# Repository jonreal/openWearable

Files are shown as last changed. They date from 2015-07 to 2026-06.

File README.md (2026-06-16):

# openWearable

A real-time hardware/software platform for wearable robotics development based on the BeagleBone platform.

## Overview

openWearable is an open-source project designed to provide a complete hardware and software solution for developing wearable robotic systems, with a focus on real-time control. The platform utilizes the TI BeagleBone Black's Programmable Real-time Units (PRUs) to achieve deterministic high-speed control loops alongside a full Linux environment.

Current/past applications include:
- Upper limb soft exosuits
- Powered ankle-foot prostheses
- Haptic feedback systems
- EMG/IMU sensing and processing

## Getting Started

### Hardware Requirements
- BeagleBone Black or BeagleBone AI64 (see arm64 branch)
- Compatible sensors (see hardware directory)
- Actuators (PAMs, motors, etc.)

### Software Dependencies
- Recommended OS: Debian Linux 12.x (Bookworm) or later
- Kernel: 5.10.168-ti-r72
- PRU Code Generation Tools

### Installation

1. Clone the repository:
   ```
   git clone https://github.com/jonreal/openWearable.git
   cd openWearable
   ```

2. Build the library first:
   ```
   cd library && make
   ```

3. Build an application:
   ```
   cd ../apps/template && make
   ```

4. Run the application:
   ```
   ./bin/template
   ```

### Device Tree Setup

The device tree configures BeagleBone hardware resources for openWearable. Follow these steps:

1. Clone the BeagleBoard-DeviceTrees repository:
   ```
   git clone https://github.com/beagleboard/BeagleBoard-DeviceTrees.git ~/BeagleBoard-DeviceTrees
   ```

2. Create a symbolic link to your device tree file:

   For BeagleBone Black:
   ```
   cd device-tree
   ln -s $PWD/am335x-boneblack-openWearable.dts ~/BeagleBoard-DeviceTrees/src/arm/
   ```

   For BeagleBone Blue:
   ```
   cd device-tree
   ln -s $PWD/am335x-boneblue-openWearable.dts ~/BeagleBoard-DeviceTrees/src/arm/
   ```

3. Compile and install the device tree:
   ```
   cd ~/BeagleBoard-DeviceTrees
   make install_arm
   ```

4. The compiled device tree files will be installed to `/boot/dtbs/<kernel>/`
   (e.g., `/boot/dtbs/5.10.168-ti-r72/`)

5. Edit `/boot/uEnv.txt` to enable the overlay:
   ```
   sudo nano /boot/uEnv.txt
   ```
   
   Add or modify the following line:
   ```
   dtb=am335x-boneblack-openWearable.dtb   # For BeagleBone Black
   # OR
   dtb=am335x-boneblue-openWearable.dtb    # For BeagleBone Blue
   ```

6. Reboot the BeagleBone:
   ```
   sudo reboot
   ```

## Network Setup
To connect to the BeagleBone to Wi-Fi, follow these steps:
   ```
   iwctl

    [iwctl]# station wlan0 scan
    [iwctl]# station wlan0 get-networks
    [iwctl]# station wlan0 connect <SSID>

   ```

## Project Structure

- `apps/` - Application examples and templates
  - `template/` - Starting point for new applications
  - Various application examples (see below)
- `library/` - Core libraries
  - `include/` - Header files
  - `src/` - CPU-side source files
  - `pru_src/` - PRU-specific source files
- `device-tree/` - Hardware configuration
- `hardware/` - PCB designs and hardware documentation
- `gui/` - Visualization tools
- `utils/` - Utility programs
- `scripts/` - Helper scripts

## Application Development

Each application consists of these core files:
- `state.h` - Memory structure definitions
- `format.c` - Logging format definitions
- `cpuloop.c` - Application CPU logic
- `uiloop.c` - User interface logic
- `pruloop.c` - PRU-specific logic

To create a new application, copy the template directory:
```
cd apps
cp -r template my_new_app
cd my_new_app
```

### Build Commands
- First build the library: `cd library && make`
- Then build the app: `cd apps/[app-name] && make`

## Recent Enhancements

1. **Build System Reorganization (March 2025)**
   - Implemented libowpru.a for sharing PRU driver code
   - Each app links against this shared library
   
2. **DMA for Data Transfer (March 2025)**
   - Added DMA support for logging with performance monitoring
   - Use `-d` flag to disable DMA for benchmarking

3. **Binary Logging (In Progress)**
   - Converting text-based logs to binary format
   - Improving performance by reducing formatting overhead

## Example Applications

- **pamtest**: Test pneumatic artificial muscles (PAMs)
- **haptic-tracking**: Haptic feedback control system
- **buttontest**: Simple I/O demonstration
- **imutest**: Test IMU sensors and data processing
- **reflex**: Demonstrate reflex control algorithms

## Publications Using openWearable

### Soft Wearable Robots for Pediatric Movement Disorders
- Realmuto J, Sanger TD. "Assisting Forearm Function in Children With Movement Disorders via A Soft Wearable Robot With Equilibrium-Point Control." Frontiers in Robotics and AI, 2022; 9:877041. doi:10.3389/frobt.2022.877041.
- Repository branch: [equilibrium-point-study](https://github.com/jonreal/openWearable/tree/equilibrium-point-study)

### Powered Ankle-Foot Prostheses
- Realmuto, J. "Towards Personalized Powered Ankle-Foot Prostheses." Dissertation, 2018.
- Repository branch: [poweredAnkle](https://github.com/jonreal/openWearable/tree/poweredAnkle)

### Haptic Feedback for Lower Limb Prostheses
- Sie A, Realmuto J, Rombokas E. "A Lower Limb Prosthesis Haptic Feedback System for Stair Descent." ASME Design of Medical Devices Conference, 2017. doi:10.1115/DMD2017-3409.
- Repository branch: [hapticFeedback](https://github.com/jonreal/openWearable/tree/hapticFeedback)

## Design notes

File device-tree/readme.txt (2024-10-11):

Use 'BeagleBoard-DeviceTrees'
https://github.com/beagleboard/BeagleBoard-DeviceTrees

ln -s <device-tree> ~/BeagleBoard-DeviceTrees/src/arm
cd ~/BeagleBoard-DeviceTrees
make install_arm

Compiled device trees:
/boot/dtbs/<kernel>/

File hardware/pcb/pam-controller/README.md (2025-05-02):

This board controls pneumatic valves using a TCA9548A I2C multiplexer and two ULN2803A driver ICs. It supports up to 8 I2C channels and 16 outputs. Logic runs at 3.3V, while VCC supplies power to the valves (e.g., 7V). Use any I2C-capable microcontroller to select channels and drive outputs through the ULN2803A.

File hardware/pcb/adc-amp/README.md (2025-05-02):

## ADD Details

This folder contains the schematic and component layout for the ADC amplifier circuit using the ADS131M08IPBS chip. The design was created in Autodesk EAGLE and is intended for precision analog signal acquisition.

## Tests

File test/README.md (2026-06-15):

# openWearable tests

Tests live here, mirroring `apps/` but kept separate from it:

- Each test builds to **`test/bin/`** (not `apps/bin/`), so test binaries never
  land on `$PATH` next to real apps.
- Test firmware uses a test-specific name (`am335x-pruN-<test>-fw`), so it never
  clobbers an app's installed firmware.

## Test form: full-OW, with a host-unit escape hatch

The default form is a **full-OW integration test**: a test is a normal openWearable
app that brings up the *entire* stack (PRU + A8 + the library it exercises) and must
**tear down cleanly** every run. On this platform the cross-core integration *is*
the product (deterministic hand-off across cores), so exercising the real assembled
system catches what a mocked unit test cannot.

To stay DRY, a test reuses the `apps/template` hooks it doesn't need to change and
supplies only the file it does. `logbench` is the model: its Makefile pulls
`state.h`, `pruloop.c`, `cpuloop.c`, `format.c`, and the `PRU*.cmd` linker scripts
from `apps/template/` via `vpath`, and provides only a headless `uiloop.c`. So
`logbench == the template app with the interactive menu swapped for a benchmark
driver`.

Reserve plain **host-compiled unit tests** (no board, no PRU) for pure-host modules
that have no hardware dependency — e.g. the `utils/logdecode` decoder or `fix16`
math. Add those under `test/<module>/` with their own host Makefile when needed.

## logbench — logging throughput benchmark

Finds the sample-rate (`fs`) at which the A8 can no longer consume PRU state fast
enough. It ramps `fs` and, at each step, runs the whole stack logging for a fixed
duration, then reports two independent "can't keep up" signals:

| signal | meaning |
|---|---|
| `DROPS` | log-ring overflow — the writer thread / disk couldn't drain the 4 MB RAM ring |
| `SAMPLE-LOSS` | PRU state-ring overflow — the fixed ~200 Hz A8 drain fell behind `fs` upstream of the log ring |

The limit is the highest `fs` with no drops and ~100% capture.

**Architecture note.** The A8 logging producer is a fixed-rate `SIGALRM` timer
(~200 Hz); raising `fs` enlarges the *batch* the A8 drains from the PRU state-ring
each tick, it does not speed the tick up. With `STATE_BUFF_LEN = 96` that gives an
A8-cadence ceiling around **96 / 0.005 s ≈ 19.2 kHz** before the PRU ring overflows —
which at 16 B/record is only ~300 KB/s, far below any eMMC limit. So on this board
the expected wall is `SAMPLE-LOSS` near ~19 kHz, not `DROPS`. Levers to push it
higher: a deeper `STATE_BUFF_LEN`, a faster A8 timer, or DMA off the state-ring.

### Run (on the board)

```sh
# builds libow_pru + logbench, then sweeps the default fs ladder to eMMC
test/logbench/run_logbench.sh

# isolate the consumer from storage: log to a tmpfs (RAM) sink
SINK=/dev/shm test/logbench/run_logbench.sh

# custom sweep / longer runs / keep the captured files
FREQS="1000 10000 19000 19500 20000" SECS=15 KEEP=1 test/logbench/run_logbench.sh
```

Each captured file is a normal openWearable binary log; decode it with
`utils/logdecode/` to inspect the `time` column for gaps.

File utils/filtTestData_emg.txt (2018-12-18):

13245
8.896693e+02
8.945045e+02
9.063726e+02
8.997792e+02
8.901089e+02
8.905485e+02
8.971418e+02
9.072517e+02
8.984605e+02
8.940649e+02
8.857133e+02
8.751638e+02
8.725265e+02
8.738452e+02
8.857133e+02
8.848342e+02
8.953836e+02
8.571418e+02
8.628561e+02
8.624166e+02
8.738452e+02
8.826364e+02
8.940649e+02
9.138451e+02
9.279110e+02
9.208781e+02
9.367022e+02
9.261528e+02
8.980209e+02
9.103286e+02
9.134055e+02
9.037352e+02
8.909880e+02
8.654935e+02
8.852737e+02
9.098890e+02
9.147242e+02
8.949440e+02
8.870320e+02
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

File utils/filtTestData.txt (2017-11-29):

5000
0.053767
0.189672
-0.213319
0.105066
0.057007
-0.099358
-0.005669
0.078231
0.408084
0.333462
-0.072198
0.372552
0.147867
0.075285
0.159325
0.073612
0.087947
0.255581
0.253760
0.260816
0.192483
0.010816
0.209514
0.307034
0.199115
0.259904
0.235326
0.138489
0.204410
0.102477
0.276221
0.078842
0.092823
0.124913
-0.082421
0.361981
0.256790
0.154897
0.373529
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

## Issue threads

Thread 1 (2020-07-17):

maxon.c bug

jonreal, 2020-07-17:
maxon motor sampling velocity / current is wrong

Closed 2025-05-02.

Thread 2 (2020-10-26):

ADC emg sampling

jonreal, 2020-10-26:
EMG raw samples aren't stored correctly

Closed 2025-05-02.

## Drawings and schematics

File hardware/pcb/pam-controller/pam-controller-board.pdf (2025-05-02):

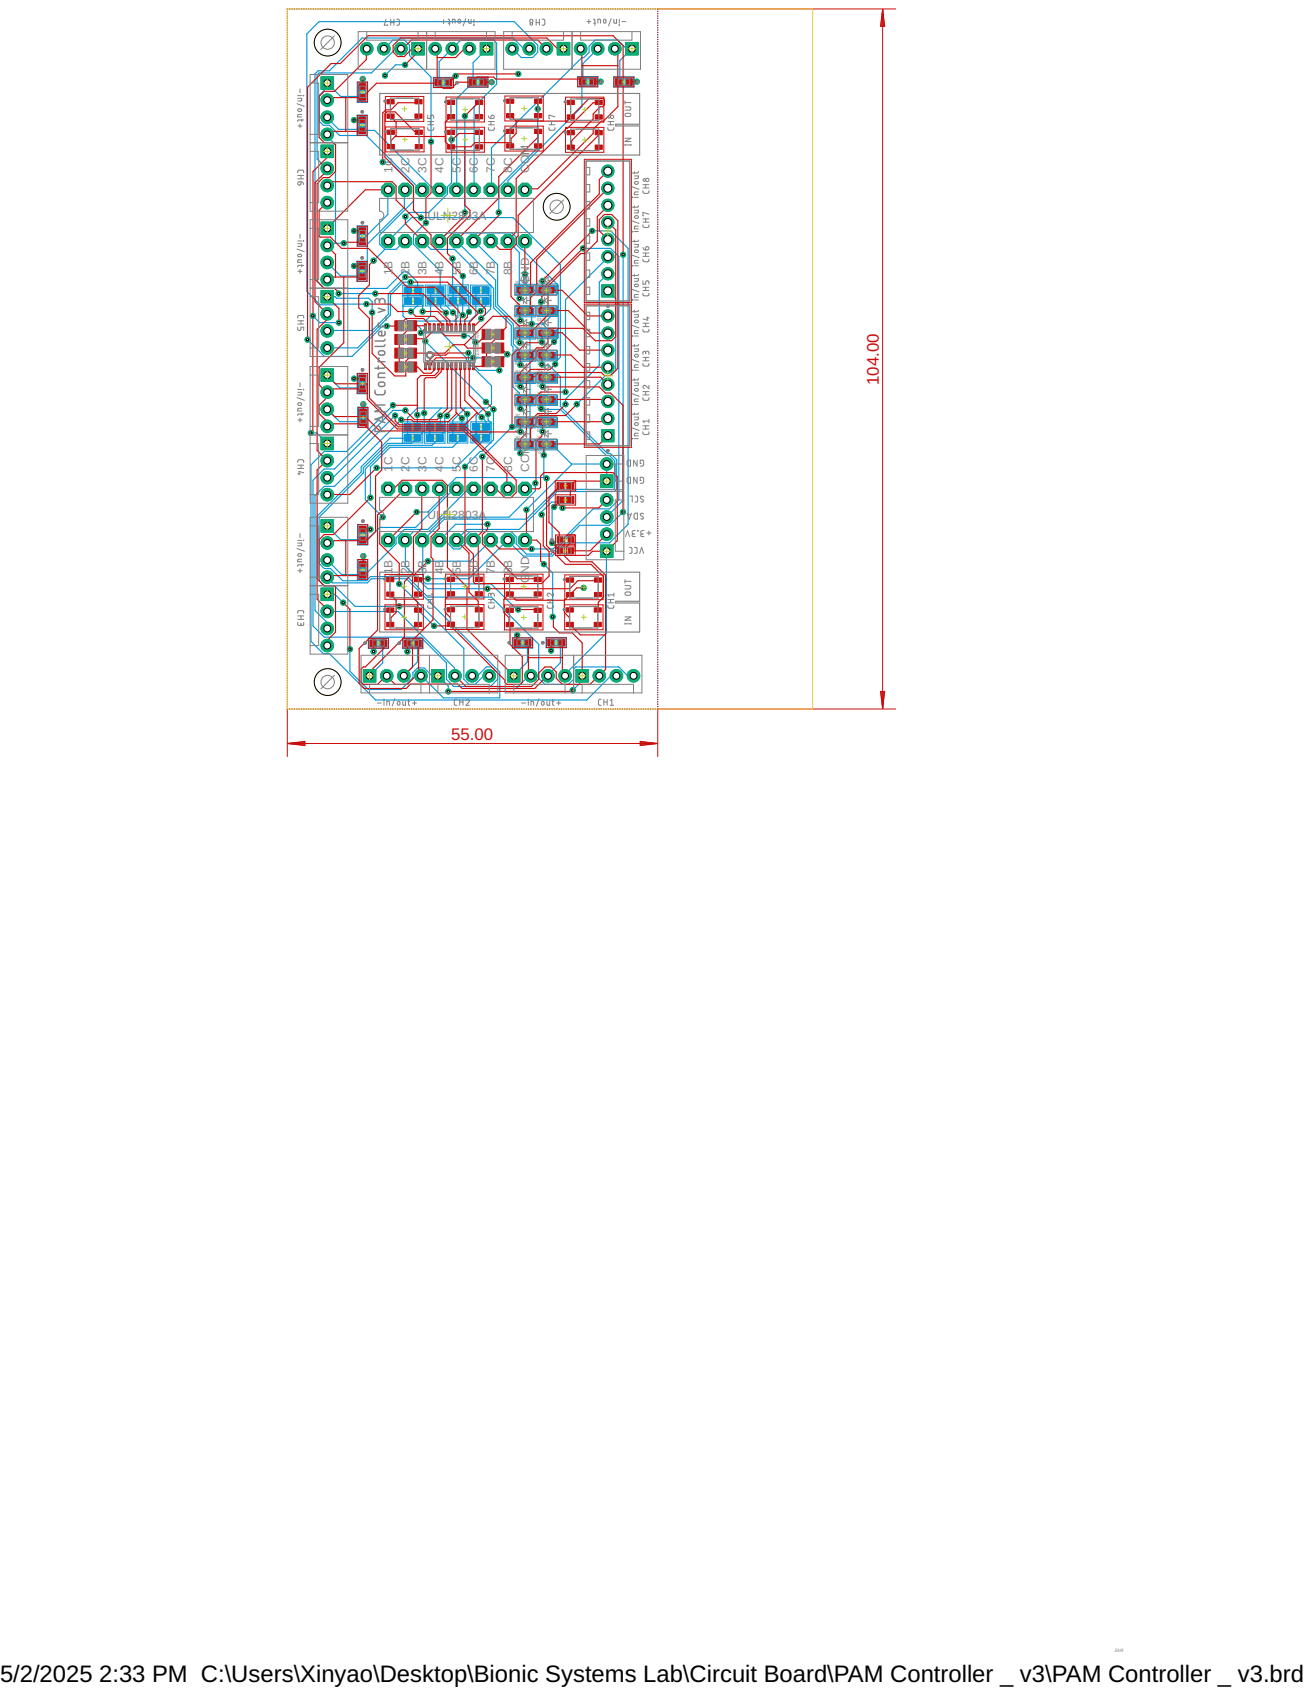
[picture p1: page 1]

5/2/2025 2:33 PM C:\Users\Xinyao\Desktop\Bionic Systems Lab\Circuit Board\PAM Controller _ v3\PAM Controller _ v3.brd

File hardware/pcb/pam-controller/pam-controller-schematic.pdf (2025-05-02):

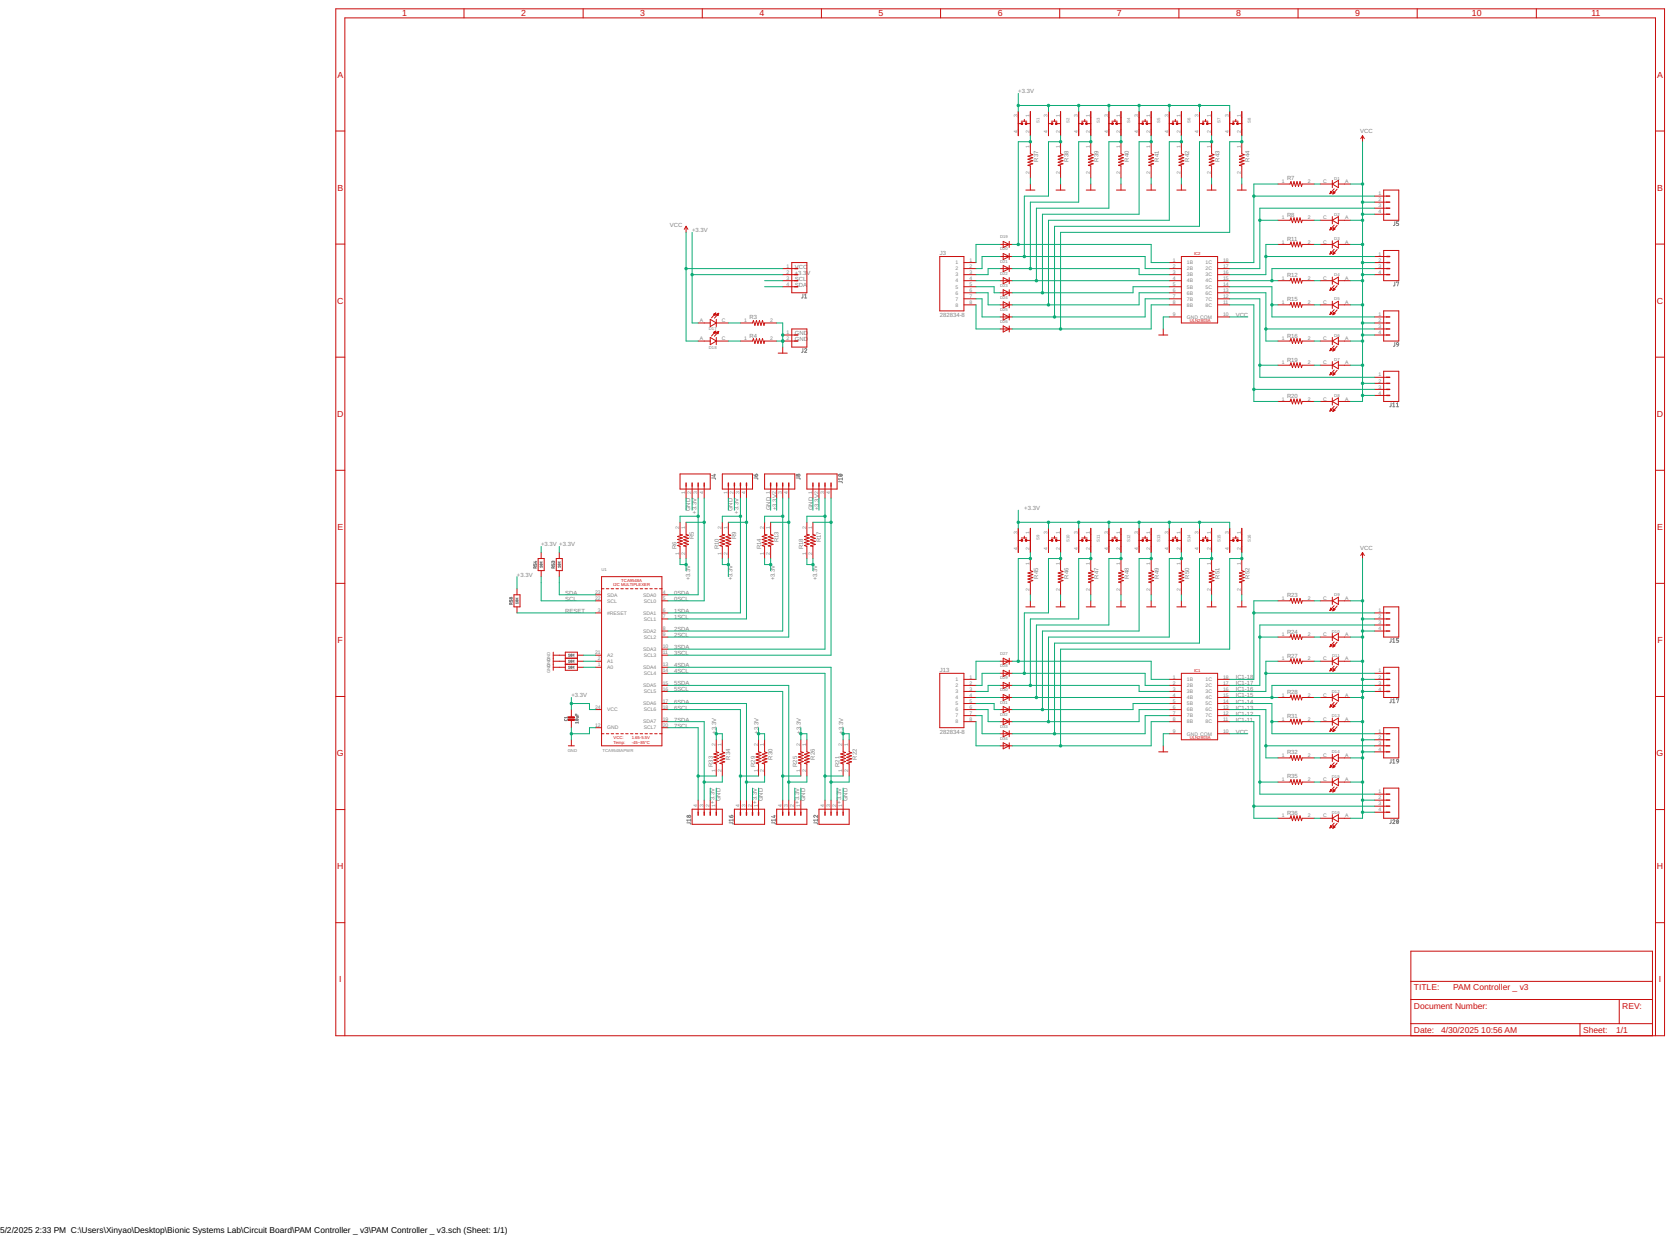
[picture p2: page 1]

GND GND GND GND GND

Document Number: | REV:

Date: 4/30/2025 10:56 AM | Sheet: 1/1

5/2/2025 2:33 PM C:\Users\Xinyao\Desktop\Bionic Systems Lab\Circuit Board\PAM Controller _ v3\PAM Controller _ v3.sch (Sheet: 1/1)

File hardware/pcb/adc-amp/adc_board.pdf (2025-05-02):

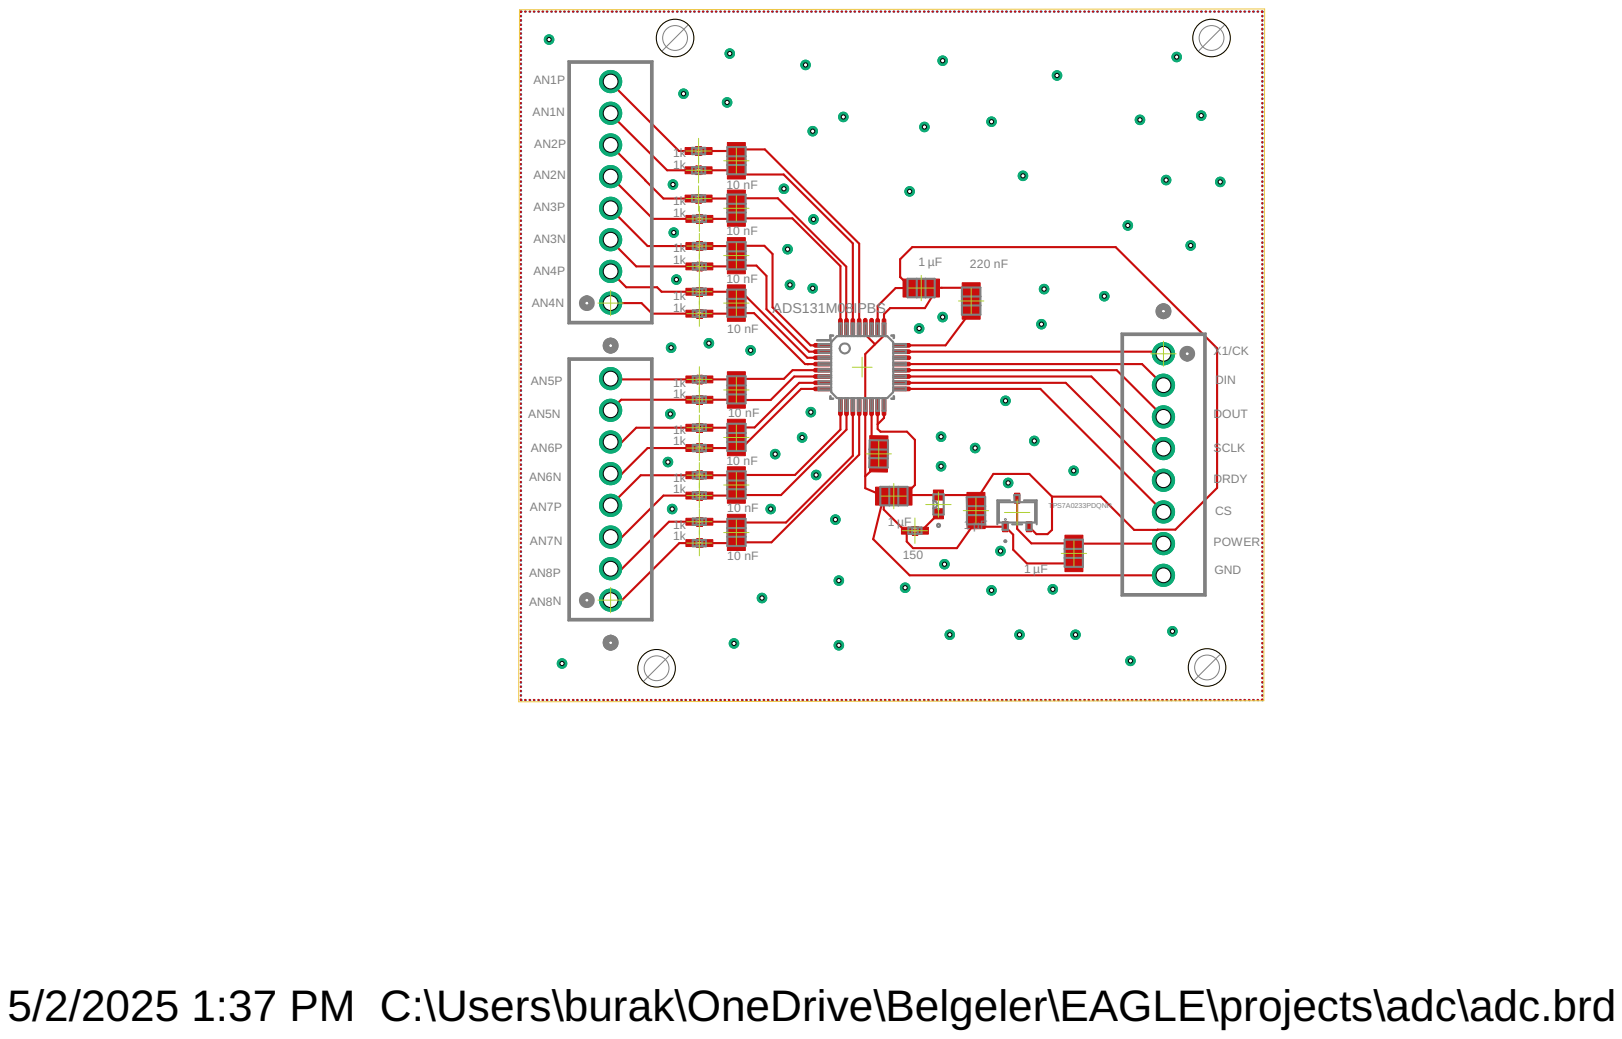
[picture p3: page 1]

SCLK CS DRDY DOUT DIN

5/2/2025 1:37 PM C:\Users\burak\OneDrive\Belgeler\EAGLE\projects\adc\adc.brd

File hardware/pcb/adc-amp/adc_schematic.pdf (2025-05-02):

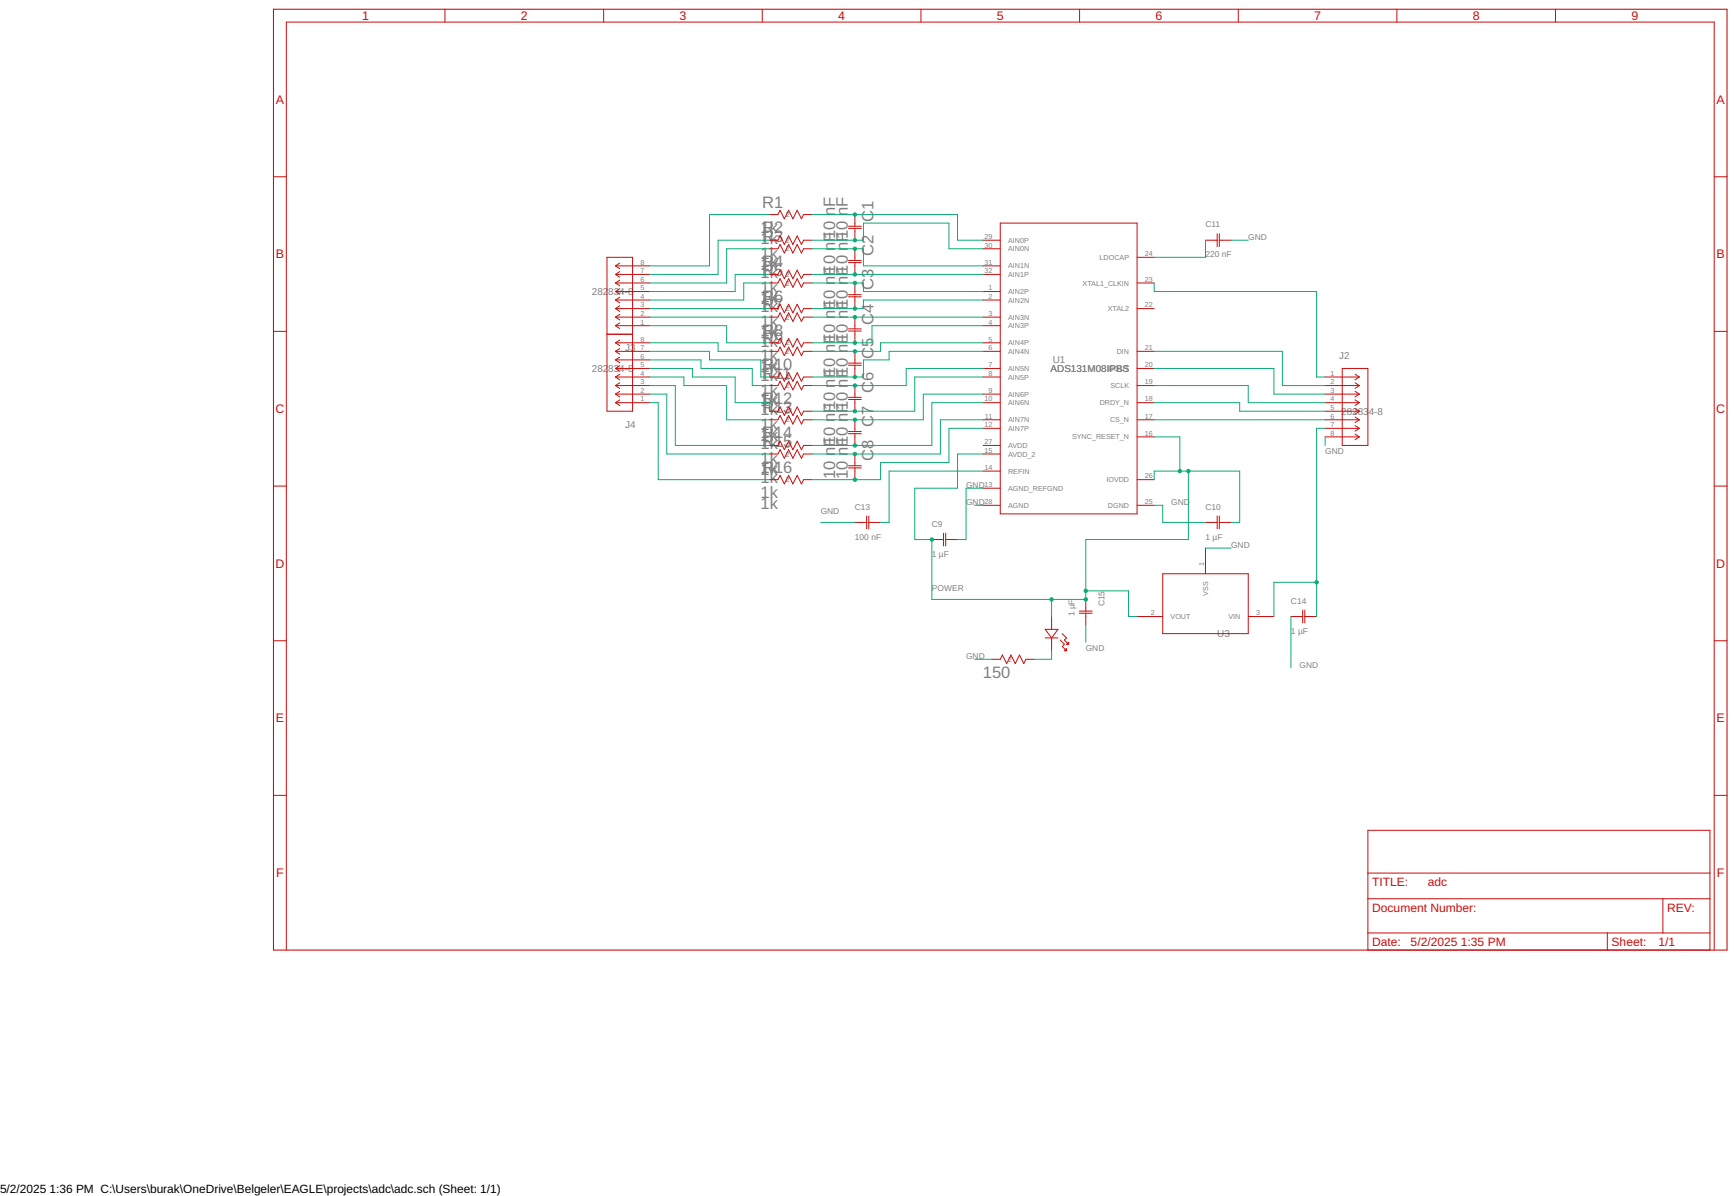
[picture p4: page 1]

Document Number: | REV:

Date: 5/2/2025 1:35 PM | Sheet: 1/1

5/2/2025 1:36 PM C:\Users\burak\OneDrive\Belgeler\EAGLE\projects\adc\adc.sch (Sheet: 1/1)

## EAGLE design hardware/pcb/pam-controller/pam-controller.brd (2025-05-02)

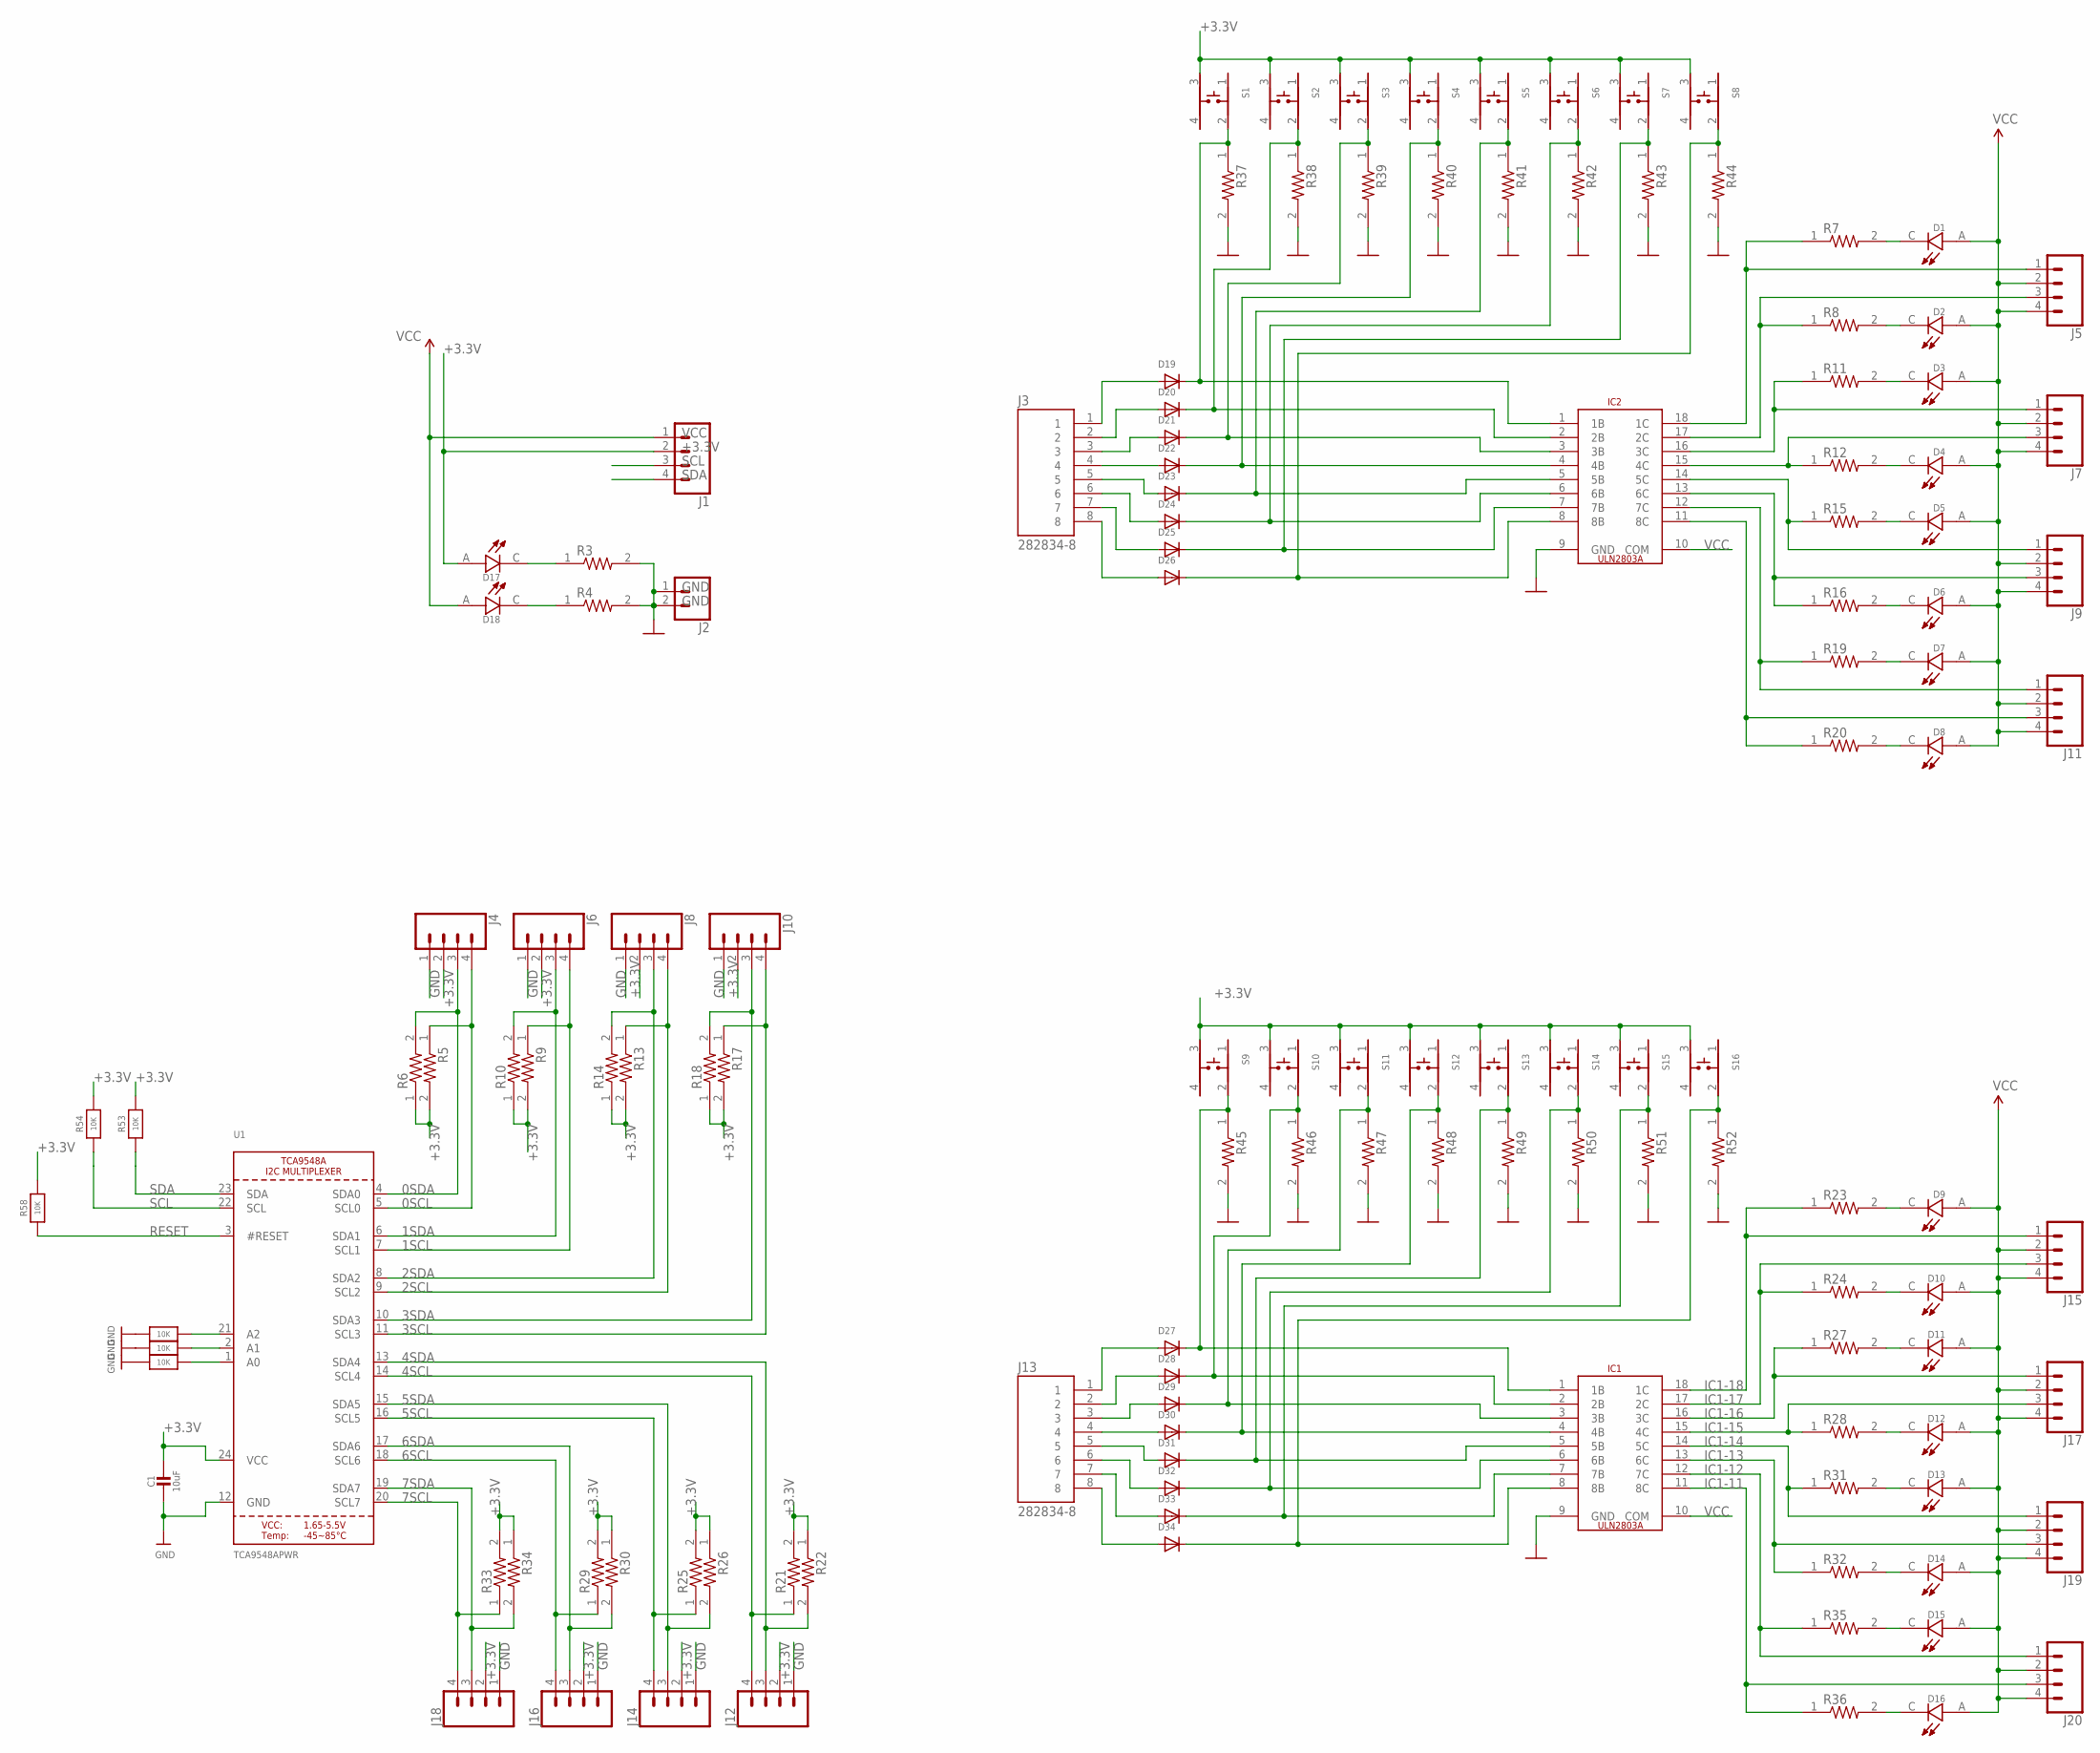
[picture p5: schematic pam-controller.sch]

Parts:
C1: 10uF; 0805-NO
D1, D2, D3, D4, D5, D6, D7, D8, D9, D10, D11, D12, D13, D14, D15, D16, D17, D18: LTST-C190KGKT; LEDC1608X35N
D19, D20, D21, D22, D23, D24, D25, D26, D27, D28, D29, D30, D31, D32, D33, D34: DIODESOD-523; SOD-523
IC1, IC2: ULN2803A
J1, J4, J5, J6, J7, J8, J9, J10, J11, J12, J14, J15, J16, J17, J18, J19, J20: CONN_04POLAR; MOLEX-1X4
J2: CONN_02POLAR; MOLEX-1X2
J3, J13: 282834-8; TE_282834-8
R3, R4, R5, R6, R7, R8, R9, R10, R11, R12, R13, R14, R15, R16, R17, R18, R19, R20, R21, R22, R23, R24, R25, R26, R27, R28, R29, R30, R31, R32, R33, R34, R35, R36, R37, R38, R39, R40, R41, R42, R43, R44, R45, R46, R47, R48, R49, R50, R51, R52: 1K; RESC1607X60N
R53, R54, R55, R56, R57, R58: 10K; 0805-NO
S1, S2, S3, S4, S5, S6, S7, S8, S9, S10, S11, S12, S13, S14, S15, S16: SKRPACE010; SW_SKRPACE010
U1: TCA9548APWR; TSSOP24

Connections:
0SCL: J4.4, R5.1, U1.5 (SCL0)
0SDA: J4.3, R6.2, U1.4 (SDA0)
1SCL: J6.4, R9.1, U1.7 (SCL1)
1SDA: J6.3, R10.2, U1.6 (SDA1)
2SCL: J8.4, R13.1, U1.9 (SCL2)
2SDA: J8.3, R14.2, U1.8 (SDA2)
3SCL: J10.4, R17.1, U1.11 (SCL3)
3SDA: J10.3, R18.2, U1.10 (SDA3)
4SCL: J12.4, R21.1, U1.14 (SCL4)
4SDA: J12.3, R22.2, U1.13 (SDA4)
5SCL: J14.4, R25.1, U1.16 (SCL5)
5SDA: J14.3, R26.2, U1.15 (SDA5)
6SCL: J16.4, R29.1, U1.18 (SCL6)
6SDA: J16.3, R30.2, U1.17 (SDA6)
7SCL: J18.4, R33.1, U1.20 (SCL7)
7SDA: J18.3, R34.2, U1.19 (SDA7)
+3.3V: C1.1, D17.A, J1.2, J4.2, J6.2, J8.2, J10.2, J12.2, J14.2, J16.2, J18.2, R5.2, R6.1, R9.2, R10.1, R13.2, R14.1, R17.2, R18.1, R21.2, R22.1, R25.2, R26.1, R29.2, R30.1, R33.2, R34.1, R53.2, R54.2, R58.2, S1.3, S2.3, S3.3, S4.3, S5.3, S6.3, S7.3, S8.3, S9.3, S10.3, S11.3, S12.3, S13.3, S14.3, S15.3, S16.3, U1.24 (VCC)
GND: C1.2, IC1.9 (GND), IC2.9 (GND), J2.1, J2.2, J4.1, J6.1, J8.1, J10.1, J12.1, J14.1, J16.1, J18.1, R3.2, R4.2, R37.2, R38.2, R39.2, R40.2, R41.2, R42.2, R43.2, R44.2, R45.2, R46.2, R47.2, R48.2, R49.2, R50.2, R51.2, R52.2, R55.2, R56.2, R57.2, U1.12 (GND)
IC1-11: IC1.11 (8C), J20.3, R36.1
IC1-12: IC1.12 (7C), J20.1, R35.1
IC1-13: IC1.13 (6C), J19.3, R32.1
IC1-14: IC1.14 (5C), J19.1, R31.1
IC1-15: IC1.15 (4C), J17.3, R28.1
IC1-16: IC1.16 (3C), J17.1, R27.1
IC1-17: IC1.17 (2C), J15.3, R24.1
IC1-18: IC1.18 (1C), J15.1, R23.1
IC2-11: IC2.11 (8C), J11.3, R20.1
IC2-12: IC2.12 (7C), J11.1, R19.1
IC2-13: IC2.13 (6C), J9.3, R16.1
IC2-14: IC2.14 (5C), J9.1, R15.1
IC2-15: IC2.15 (4C), J7.3, R12.1
IC2-16: IC2.16 (3C), J7.1, R11.1
IC2-17: IC2.17 (2C), J5.3, R8.1
IC2-18: IC2.18 (1C), J5.1, R7.1
unnamed: D19.K (C), IC2.1 (1B), R37.1, S1.2
unnamed: D19.A, J3.1
unnamed: D20.A, J3.2
unnamed: D21.A, J3.3
unnamed: D22.A, J3.4
unnamed: D23.A, J3.5
unnamed: D24.A, J3.6
unnamed: D25.A, J3.7
unnamed: D27.A, J13.1
unnamed: D27.K (C), IC1.1 (1B), R45.1, S9.2
unnamed: R56.1, U1.2 (A1)
unnamed: R57.1, U1.1 (A0)
unnamed: D28.K (C), IC1.2 (2B), R46.1, S10.2
unnamed: R55.1, U1.21 (A2)
unnamed: D30.A, J13.4
unnamed: D28.A, J13.2
unnamed: D29.A, J13.3
unnamed: D34.A, J13.8
unnamed: D33.A, J13.7
unnamed: D14.C, R32.2
unnamed: D15.C, R35.2
unnamed: D26.A, J3.8
unnamed: D32.A, J13.6
unnamed: D20.K (C), IC2.2 (2B), R38.1, S2.2
unnamed: D21.K (C), IC2.3 (3B), R39.1, S3.2
unnamed: D22.K (C), IC2.4 (4B), R40.1, S4.2
unnamed: D23.K (C), IC2.5 (5B), R41.1, S5.2
unnamed: D24.K (C), IC2.6 (6B), R42.1, S6.2
unnamed: D25.K (C), IC2.7 (7B), R43.1, S7.2
unnamed: D26.K (C), IC2.8 (8B), R44.1, S8.2
unnamed: D29.K (C), IC1.3 (3B), R47.1, S11.2
unnamed: D31.A, J13.5
unnamed: D30.K (C), IC1.4 (4B), R48.1, S12.2
unnamed: D31.K (C), IC1.5 (5B), R49.1, S13.2
unnamed: D32.K (C), IC1.6 (6B), R50.1, S14.2
unnamed: D33.K (C), IC1.7 (7B), R51.1, S15.2
unnamed: D34.K (C), IC1.8 (8B), R52.1, S16.2
unnamed: D16.C, R36.2
unnamed: D12.C, R28.2
unnamed: D13.C, R31.2
unnamed: D11.C, R27.2
unnamed: D10.C, R24.2
unnamed: D9.C, R23.2
unnamed: D8.C, R20.2
unnamed: D7.C, R19.2
unnamed: D6.C, R16.2
unnamed: D1.C, R7.2
unnamed: D17.C, R3.1
unnamed: D18.C, R4.1
unnamed: D5.C, R15.2
unnamed: D4.C, R12.2
unnamed: D3.C, R11.2
unnamed: D2.C, R8.2
RESET: R58.1, U1.3 (#RESET)
SCL: J1.4, R54.1, U1.22 (SCL)
SDA: J1.3, R53.1, U1.23 (SDA)
VCC: D1.A, D2.A, D3.A, D4.A, D5.A, D6.A, D7.A, D8.A, D9.A, D10.A, D11.A, D12.A, D13.A, D14.A, D15.A, D16.A, D18.A, IC1.10 (COM), IC2.10 (COM), J1.1, J5.2, J5.4, J7.2, J7.4, J9.2, J9.4, J11.2, J11.4, J15.2, J15.4, J17.2, J17.4, J19.2, J19.4, J20.2, J20.4

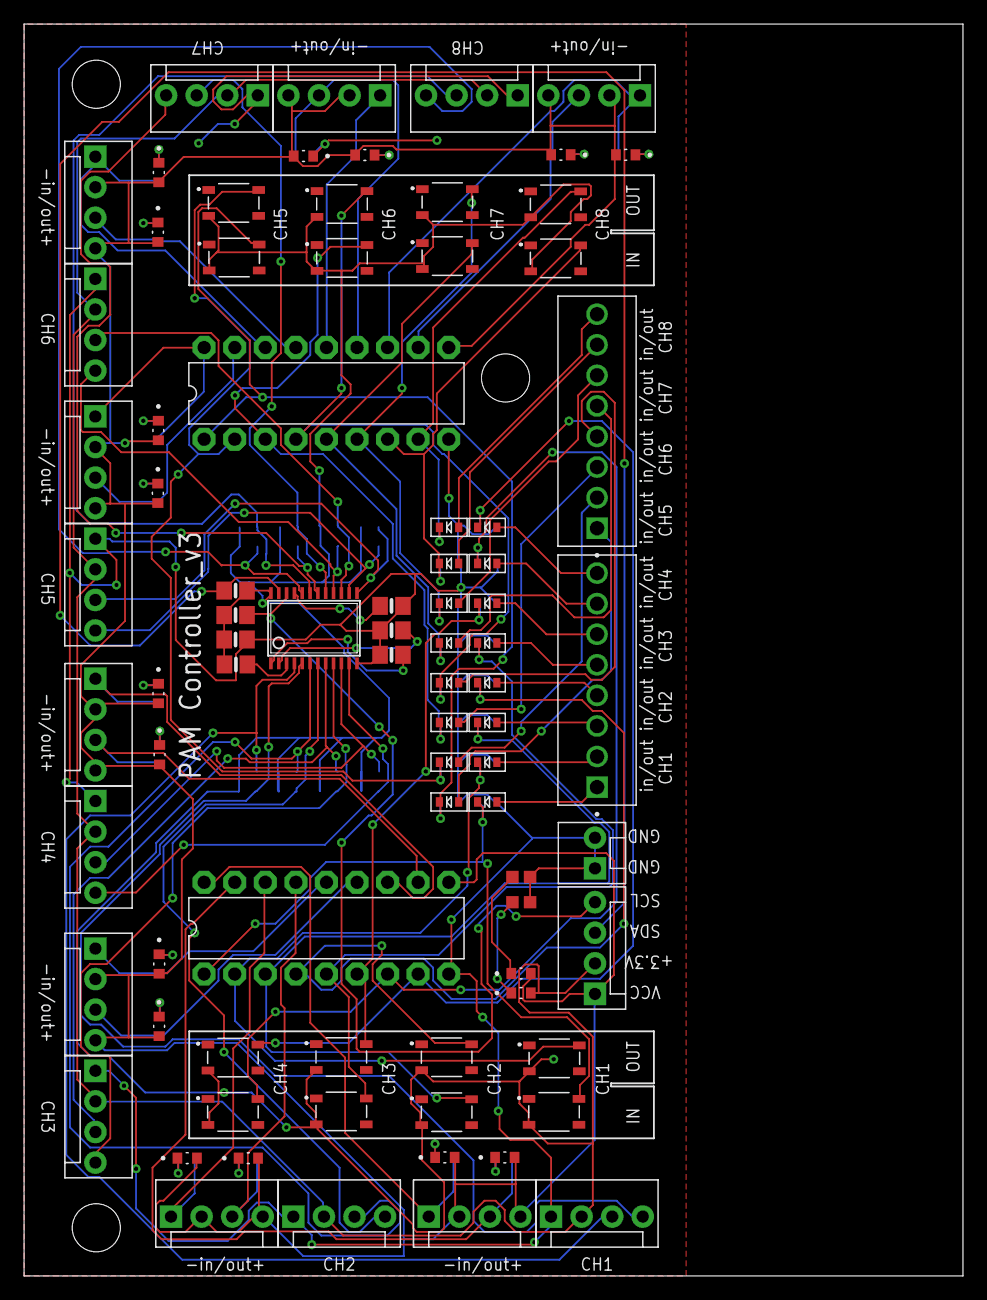
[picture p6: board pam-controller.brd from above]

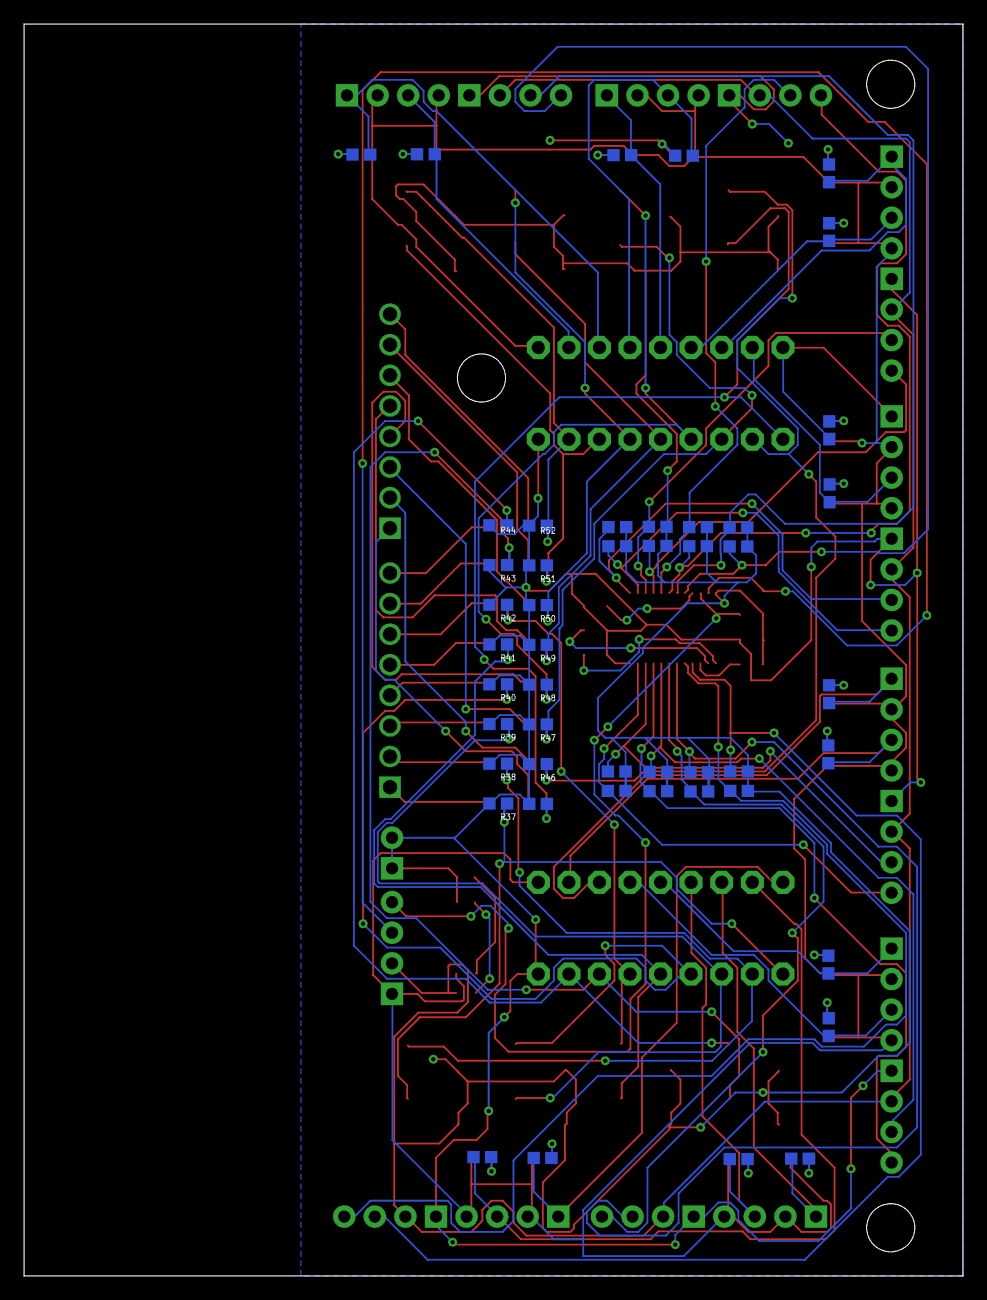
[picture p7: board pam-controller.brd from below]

Board: 2 copper layers, 78.0 x 104.0 mm, 130 parts (48 on the bottom side), 91 nets.

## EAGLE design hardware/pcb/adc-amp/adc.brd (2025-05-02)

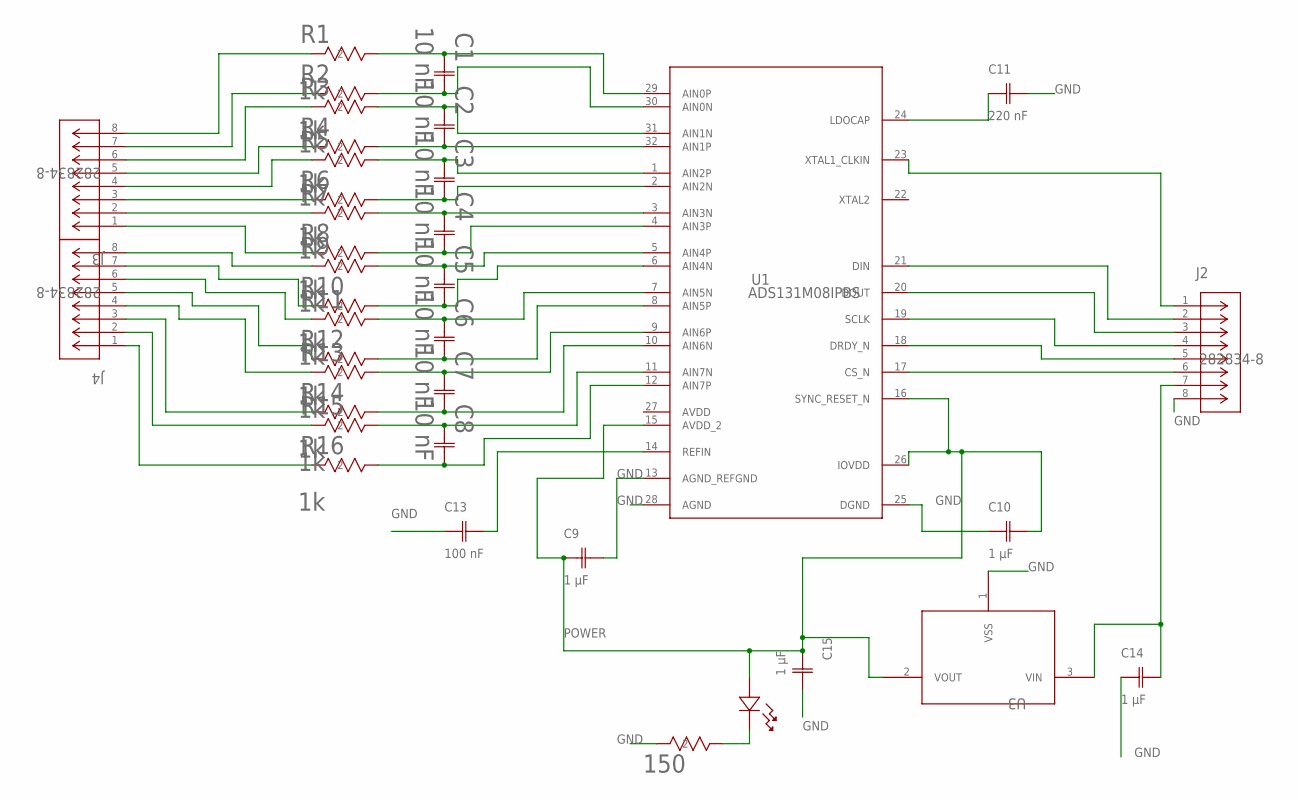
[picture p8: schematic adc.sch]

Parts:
C1, C2, C3, C4, C5, C6, C7, C8: 10 nF; CAPC220145_88N_KEM
C9, C10, C14, C15: 1 µF; CAPC220145_140N_KEM
C11: 220 nF; CAPC220145_100N_KEM
C13: 100 nF; CAPC220145_88N_KEM
J2, J3, J4: 282834-8; CONN_282834-8_TEC
LED1: LTST-C190KFKT; LED_LSTS-C190_LTO
R1, R2, R3, R4, R5, R6, R7, R8, R9, R10, R11, R12, R13, R14, R15, R16: 1k; RC0402N_YAG-M
R18: 150; RC0402N_YAG-M
U1: ADS131M08IPBS; PBS0032A_N
U3: XC6206P332MR-GSOT-23_TOR-L; SOT-23_TOR-L

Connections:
AVDD: U1.27 (AVDD)
GND: C9.2, C10.1, C11.2, C13.1, C14.1, C15.2, J2.8, R18.2, U1.13 (AGND_REFGND), U1.25 (DGND), U1.28 (AGND), U3.1 (VSS)
unnamed: C1.1, R1.1, U1.29 (AIN0P)
unnamed: C1.2, R2.1, U1.30 (AIN0N)
unnamed: C2.1, R3.1, U1.31 (AIN1N)
unnamed: C2.2, R4.1, U1.32 (AIN1P)
unnamed: C3.1, R5.1, U1.1 (AIN2P)
unnamed: C3.2, R6.1, U1.2 (AIN2N)
unnamed: C4.1, R7.1, U1.3 (AIN3N)
unnamed: C4.2, R8.1, U1.4 (AIN3P)
unnamed: C5.1, R9.1, U1.5 (AIN4P)
unnamed: C5.2, R10.1, U1.6 (AIN4N)
unnamed: C6.1, R11.1, U1.7 (AIN5N)
unnamed: C6.2, R12.1, U1.8 (AIN5P)
unnamed: C7.1, R13.1, U1.9 (AIN6P)
unnamed: C7.2, R14.1, U1.10 (AIN6N)
unnamed: C8.1, R15.1, U1.11 (AIN7N)
unnamed: C8.2, R16.1, U1.12 (AIN7P)
unnamed: C11.1, U1.24 (LDOCAP)
unnamed: J2.1, U1.23 (XTAL1_CLKIN)
unnamed: J3.8, R1.2
unnamed: J3.7, R2.2
unnamed: J3.6, R3.2
unnamed: J3.5, R4.2
unnamed: J3.4, R5.2
unnamed: J3.3, R6.2
unnamed: J3.2, R7.2
unnamed: J3.1, R8.2
unnamed: J4.8, R9.2
unnamed: J4.7, R10.2
unnamed: J4.6, R11.2
unnamed: J4.5, R12.2
unnamed: J4.4, R13.2
unnamed: J4.3, R14.2
unnamed: J4.2, R15.2
unnamed: J4.1, R16.2
unnamed: J2.4, U1.19 (SCLK)
unnamed: J2.6, U1.17 (CS_N)
unnamed: J2.5, U1.18 (DRDY_N)
unnamed: J2.3, U1.20 (DOUT)
unnamed: J2.2, U1.21 (DIN)
unnamed: C13.2, U1.14 (REFIN)
unnamed: LED1.1 (CATHODE), R18.1
unnamed: C14.2, J2.7, U3.3 (VIN)
POWER: C9.1, C10.2, C15.1, LED1.2 (ANODE), U1.15 (AVDD_2), U1.16 (SYNC_RESET_N), U1.26 (IOVDD), U3.2 (VOUT)

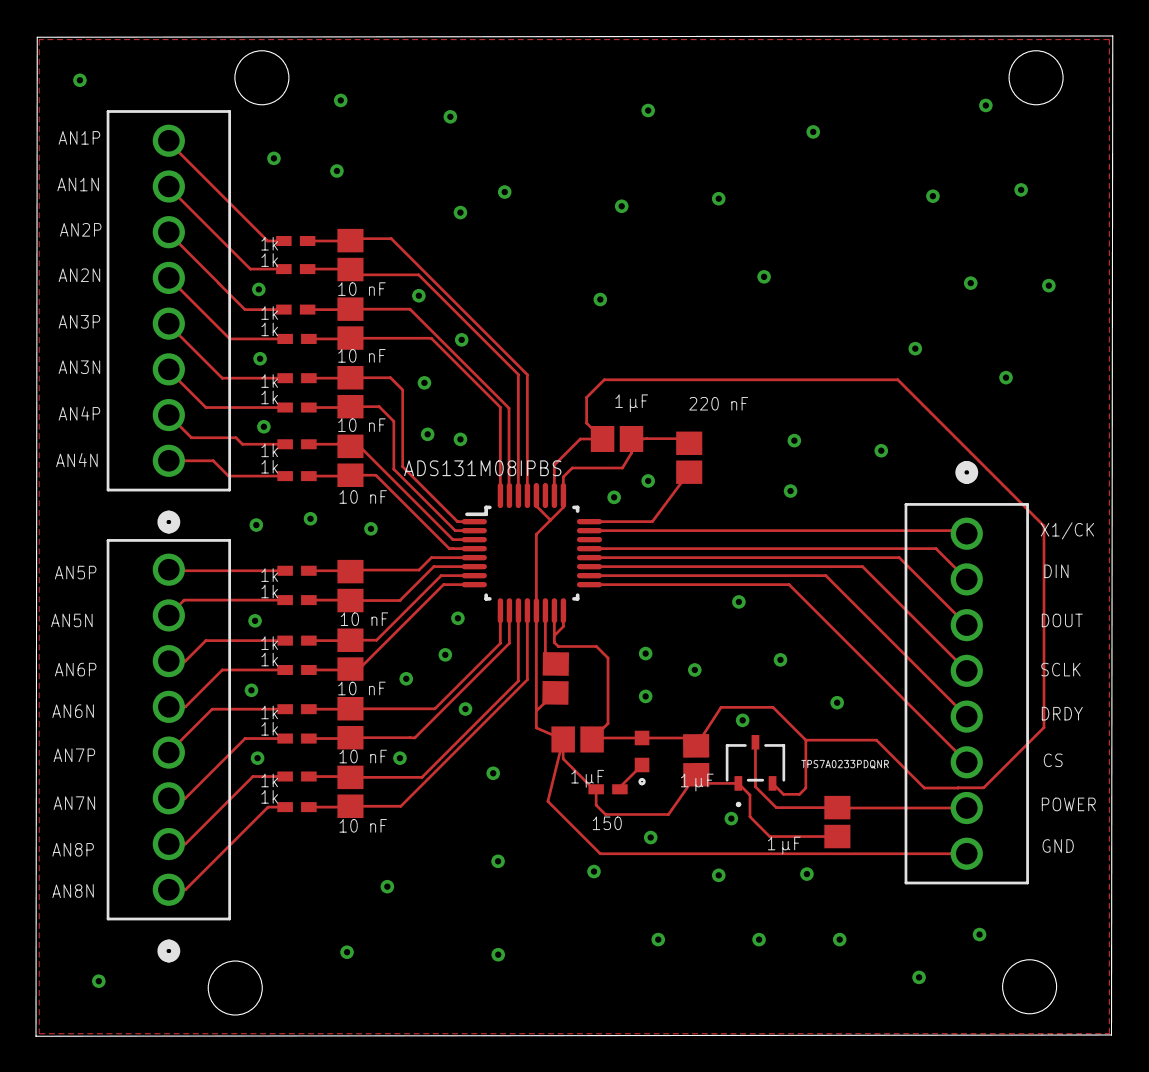
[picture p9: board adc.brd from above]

Board: 2 copper layers, 59.8 x 55.6 mm, 37 parts (0 on the bottom side), 44 nets.

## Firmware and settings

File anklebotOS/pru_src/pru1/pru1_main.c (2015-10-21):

#include <stdlib.h>
#include <stdint.h>
#include <pru_cfg.h>
#include <pru_ctrl.h>
#include <pru_iep.h>
#include <pru_intc.h>

#include "rsc_table.h"
#include "mem_types.h"
#include "hw_types.h"

#define PWM_SS2_BASE      0x48304000
#define EPWM2_BASE        0x48304200

/* Prototypes -------------------------------------------------------------- */
void updateControl(uint32_t cnt, uint8_t bi, uint8_t si);
void interruptInit(void);
void clearInterrupt(void);
void pru1ToArmInterrupt(void);
void pwmInit(void);
void disablePwm(void);
void setDuty(float duty, volatile uint16_t *motorDuty);

/* Globals ----------------------------------------------------------------- */
volatile register uint32_t __R30;
volatile register uint32_t __R31;

volatile far pruIntc CT_INTC
  __attribute__((cregister("PRU_INTC", far), peripheral));

volatile pruCfg CT_CFG
  __attribute__((cregister("PRU_CFG", near), peripheral));

volatile far pruIep CT_IEP
  __attribute__((cregister("PRU_IEP", near), peripheral));

/* State pointer */
shared_mem_t *p;

/* Param pointer */
param_mem_t *param;

/* Feedforward lookup table pointer */
ff_mem_t *ff;

/* Debug Buffer */
volatile uint32_t *debugBuffer;

/* Main ---------------------------------------------------------------------*/
int main(void)
{
  void *ptr = NULL;

  uint32_t cnt = 0;
  uint8_t stateIndx = 0;
  uint8_t buffIndx = 0;

  /*** Init Pru ***/

  /* Clear SYSCFG[STANDBY_INIT] to enable OCP master port */
  CT_CFG.SYSCFG_bit.STANDBY_INIT = 0;

  /* Pin Mux */
  CT_CFG.GPCFG0 = 0;

  /*** Memory Setup ***/

  /* Memory map for shared memory */
  ptr = (void *)PRU_L_SHARED_DRAM;
  p = (shared_mem_t *) ptr;

  /* Memory map for parameters (pru0 DRAM)*/
  ptr = (void *) PRU_OTHER_DRAM;
  param = (param_mem_t *) ptr;

  /* Memory map for feedforward lookup table (pru1 DRAM)*/
  ptr = (void *) PRU_DRAM;
  ff = (ff_mem_t *) ptr;

  /* Point global debug buffer */
  debugBuffer = &(param->debugBuffer[0]);

  /* Init */
  interruptInit();
  pwmInit();

  /*** Wait for host interrupt ***/
  while( (__R31 & HOST1_MASK) == 0){}

  clearInterrupt();

  /*** Loop ***/
  while(1){

    /* Poll of IEP timer interrupt */
    while((CT_INTC.SECR0 & (1 << 7)) == 0);

    /* Pin High */
    __R30 |= (1 << PRU1_DEBUG_PIN);

    /* Update State */
    //updateState(cnt, buffIndx, stateIndx);
    __delay_cycles(10000);

    /* Poll for pru0 done bit (updating state)*/
    while(!(p->cntrl_bit.pru0_done));

    /* Reset pru0 done bit */
    p->cntrl_bit.pru0_done = 0;

    /* Update Control */
    updateControl(cnt, buffIndx, stateIndx);

    /* Set done bit (control update done) */
    p->cntrl_bit.pru1_done = 1;

    /* Increment state index */
    cnt++;
    stateIndx++;
    if(stateIndx == SIZE_OF_BUFFS){
      stateIndx = 0;
      buffIndx++;
      if(buffIndx == NUM_OF_BUFFS){
        buffIndx = 0;
      }
    }

    /* Check enable bit */
    if(!(p->cntrl_bit.shdw_enable))
        break;

    /* Wait till interrupt is cleared */
    while(CT_INTC.SECR0 & (1 << 7));

    /* Pin Low */
    __R30 &= ~(1 << PRU1_DEBUG_PIN);
  }

  /* Pin Low */
  __R30 &= ~(1 << PRU1_DEBUG_PIN);

  /* Disable pwm */
  disablePwm();

  /* Clear all interrupts */
  clearInterrupt();
  CT_INTC.SECR0 = 0xFFFFFFFF;
  CT_INTC.SECR1 = 0xFFFFFFFF;

  /* Wait for Host Interrupt */
//  while( (__R31 & HOST1_MASK) == 0){}

//  __delay_cycles(1000);

  /* Send interrupt to ARM */
//  pru1ToArmInterrupt();

  __halt();
  return 0;
}

void updateControl(uint32_t cnt, uint8_t bi, uint8_t si)
{

  setDuty(50.0, &(p->state[bi][si].motorDuty));

}



void pwmInit(void)
{
  /* T_tbclk = PWM_CLK/CLK_DIV
   *
   * For up-down-count mode
   *    T_pwm = 2 x TBPRD x T_tbclk
   *    F_pwm = 1 / T_pwm
   *
   * PWM resolution
   *    Res (%) = F_pwm/F_sysclkout X 100
   *    Res (bits) = log2(F_pwm/F_sysclkout) */

  /* TODO: make this a param */
  uint16_t pwm_prd = 10000;

  /* Disable Global enable interrupts */
  CT_INTC.GER = 0;

  /**** PWM SS 2 registers *****/

  /* CLKCONFIG: ePWMCLK_EN = 0x1 - enable pwm clk
   *            eQEPCLKSTOP_REQ = 0x1 - disable qep clk
   *            eCAPCLKSTOP_REQ = 0x1 - disable cap clk */
  HWREG(PWM_SS2_BASE + 0x8) = (0x1 << 8) | (0x1 << 5) | (0x1 << 1);

  /**** EPWM registers *****/

  /* CMPCTL: SHDWAMODE = 0x1 - no shadow mode */
  HWREGH(EPWM2_BASE + 0xE) = (0x1 << 4);

  /* CMPA: compare reg */
  HWREGH(EPWM2_BASE + 0x12) = pwm_prd;

  /* CMPAHR: high res compare reg */
  HWREGH(EPWM2_BASE + 0x10) = 0x1;

  /* AQCTLA:  CAD = 0x1 - when cnt = compare (increasing) force EPWMxA high
   *          CAU = 0x2 - when cnt = compare (decreasing) force EPWMxA high */
  HWREGH(EPWM2_BASE + 0x16) = (0x1 << 6) | (0x2 << 4);

  /* TBCTL: PRDLD = 0x1 - shadow prd off
   *        CTRMODE = 0x2 - up-down-cnt mode */
  HWREGH(EPWM2_BASE) = (0x1 << 3) | 0x2;

  /* TBPRD: set period */
  HWREGH(EPWM2_BASE + 0xA) = pwm_prd;

  /*ETCLR: clear interrupts */
  HWREGH(EPWM2_BASE + 0x38) = 0x1;

  /*ETSEL: INTEN = 0x1 -  enable pwm interrupt */
  HWREGH(EPWM2_BASE + 0x32) = (0x1 << 3);

  /* Globaly enable interrupts */
  CT_INTC.GER = 1;
}

void setDuty(float duty, volatile uint16_t *motorDuty)
{
  /* Store duty command */
  *motorDuty = (uint16_t) (duty * 10.0);

  /* Calculate compare value */
  uint16_t cmpvalue = (uint16_t) (-100.0*duty + 10000.0);

  /* CMPA: compare register */
  HWREGH(EPWM2_BASE + 0x12) = cmpvalue;
}

void disablePwm(void)
{
  /* TODO: fix this */

  /* TBPRD: period = 0 */
  HWREGH(EPWM2_BASE + 0xA) = 0x1;

  /* CMPA: compare reg */
  HWREGH(EPWM2_BASE + 0x12) = 0x1;
}


void interruptInit(void)
{
  /* Disable Global enable interrupts */
  CT_INTC.GER = 0;

  /* Clear any pending PRU-generated events */
  __R31 = 0x00000000;

  /* Clear the status of all interrupts */
  CT_INTC.SECR0 = 0xFFFFFFFF;
  CT_INTC.SECR1 = 0xFFFFFFFF;

  /* Gloablly enable interrupts */
  CT_INTC.GER = 1;
}

void pru1ToArmInterrupt(void)
{
  __R31 = PRU1_ARM_INT;
}

void clearInterrupt(void)
{
    __R31 = 0x00000000;
}

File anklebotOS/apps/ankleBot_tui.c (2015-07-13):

#include <stdlib.h>
#include <stdio.h>
#include <stdint.h>
#include <sys/time.h>
#include <unistd.h>
#include <signal.h>
#include <string.h>
#include <pthread.h>
#include <fcntl.h>
#include <unistd.h>
#include <sys/ioctl.h>
#include <linux/spi/spidev.h>
#include <math.h>

#include "pinconfig.h"
#include "control.h"
#include "motor.h"
#include "spi.h"

#define ANKLE_OS_v 1

const int debug = 0;

int main(int argc, char *argv[])
{
  const float frq_hz = 200;
  static FILE* f_log;

  printf("\n---------------------\n");
  printf("Welcome to AnkleOS\n");
  printf("---------------------\n");

  if(init_control(frq_hz, f_log) != 0){
    perror("controller initialization failed.");
    return -1;
  }

  if(start_control() != 0){
    perror("controller start failed.");
    return -1;
  }

  ui_menu_cb();
  while(1){
    pause();
    ui_input();
  }
}

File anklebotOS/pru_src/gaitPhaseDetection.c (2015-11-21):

#include <stdint.h>

#include "mem_types.h"
#include "gaitPhaseDetection.h"


/* Stuct */
gp_t gp;


void gaitPhaseInit(param_mem_t* params)
{
  gp.toe_hs = params->gp_toe_hs;
  gp.mid_hs = params->gp_mid_hs;
  gp.heel_hs = params->gp_heel_hs;
  gp.toe_to = params->gp_toe_to;
  gp.mid_to = params->gp_mid_to;
  gp.heel_to = params->gp_heel_to;

  if(params->gpOnLeftFoot){
    gp.toe_indx = 2;
    gp.mid_indx = 3;
    gp.heel_indx = 4;
  }
  else{
    gp.toe_indx = 5;
    gp.mid_indx = 6;
    gp.heel_indx = 7;
  }

  gp.prevGaitPhase = 0;
  gp.prevAvgPeriod = 0;
  gp.period[0] = 0;
  gp.period[1] = 0;
  gp.period[2] = 0;
}

void gaitPhaseUpdateParams(param_mem_t *params)
{
  gp.toe_hs = params->gp_toe_hs;
  gp.mid_hs = params->gp_mid_hs;
  gp.heel_hs = params->gp_heel_hs;
  gp.toe_to = params->gp_toe_to;
  gp.mid_to = params->gp_mid_to;
  gp.heel_to = params->gp_heel_to;
}

void gaitPhaseDetect(volatile uint32_t cnt,
                     volatile uint16_t *gaitPhase,
                     volatile uint16_t *avgPeriod,
                     volatile uint16_t *adc)
{
  /* 0 - unknown
   * 1 - stance
   * 2 - swing */

  /* Unkown, wait for HS */
  if(gp.prevGaitPhase == 0){
    if(isHeelStrike(adc)){
      *gaitPhase = 1;
      *avgPeriod = gp.prevAvgPeriod;
    }
    else {
      *gaitPhase = gp.prevGaitPhase;
      *avgPeriod = gp.prevAvgPeriod;
    }
  }

  /* Stance, wait for TO */
  else if(gp.prevGaitPhase == 1){
    if(isToeOff(adc)){
      *gaitPhase = 2;
      *avgPeriod = gp.prevAvgPeriod;
    }
    else {
      *gaitPhase = gp.prevGaitPhase;
      *avgPeriod = gp.prevAvgPeriod;
    }
  }

  /* Swing, wait for HS */
  else if(gp.prevGaitPhase == 2){
    if(isHeelStrike(adc)){
      *gaitPhase = 1;

      /* Circular Buffer for average period */
      gp.period[2] = gp.period[1];
      gp.period[1] = gp.period[0];
      gp.period[0] = cnt - gp.period[0];

      /* Average Period */
      *avgPeriod = (gp.period[0] + gp.period[1] + gp.period[2])/3;
    }
    else {
      *gaitPhase = gp.prevGaitPhase;
      *avgPeriod = gp.prevAvgPeriod;
    }
  }
  gp.prevGaitPhase = *gaitPhase;
  gp.prevAvgPeriod = *avgPeriod;
}


uint16_t isHeelStrike(volatile uint16_t* adc)
{
  if( (adc[gp.heel_indx] > gp.heel_hs)
        & (adc[gp.mid_indx] < gp.mid_hs)
        & (adc[gp.toe_indx] < gp.toe_hs) ){
    return 1;
  }
  else{
    return 0;
  }
}

uint16_t isToeOff(volatile uint16_t* adc)
{
  if( (adc[gp.toe_indx] < gp.toe_to)
        & (adc[gp.heel_indx] < gp.heel_to)
        & (adc[gp.mid_indx] < gp.mid_to) ){
    return 1;
  }
  else{
    return 0;
  }
}

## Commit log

2015-09-11 ADC works on pru.
2015-09-16 PWM working from pru.
2015-09-17 SPI working on PRU.
2015-09-23 Encoder with SPI working, but seems to be the bottle neck in terms of speed...
2015-09-24 Working on i2c - no luck yet.
2015-09-25 Still working on i2c! It's a little bitch.
2015-09-29 i2c works now, except bus protocol is wrong. See imu datasheet.
2015-09-30 i2c works, still need to implement i2cTxByte and i2cRxBurst.
2015-10-02 i2c works, but decided to use TI drivers - better solution.
2015-10-02 TI i2c driver added, not working yet tho.
2015-10-07 i2c works but dcount not right on burst reads...
2015-10-08 i2c works, sampling at 1 kHz
2015-10-12 Add TI drivers to project.
2015-10-14 Started using TI drivers. i2c is done, but spi, adc, pwm aren't.
2015-10-21 Both prus using timer now.
2015-11-05 Wifi script prints new ip now.
2015-11-06 Update device tree with new pins and adcdriver.h with pin assignment.
2015-11-12 Working on fixing motor_demand_current to pwm_compare_value, almost done
    [pru1_main.c]
2015-11-17 Lot's of stuff, tui plus motor stuff.
2015-11-18 Started on gaitPhase, not working yet.
    [gaitPhaseDetection.c, pru1_main.c]
2015-11-20 Lookup table has problems
    [pru1_main.c]
2015-11-21 Fixed array index out of range problem.
    [pru1_main.c]
2015-11-24 Gait phase is close, but not working, lookup table is also not working correctly.
    [pru1_main.c]
2015-12-01 Gait phase and motor lookup working.
2015-12-01 Updated device tree for sync pin -- pull down.
2016-01-13 SPI1_0 CS is broken, so switch to SPI1_1, and fixed padding in mem_types for debugBuffer.
    [pru1_main.c]
2016-01-14 Really commit for Jan 14 2016 experiment -- higher power supply voltage - better
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2016-01-22 Added filters, commit for Jan 22 PA test.
2016-02-04 Working on filter coefficients.
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2016-02-08 Deleteted old filter files.
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2016-02-11 Fixed point lib in action.
    [pru1_main.c]
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2016-02-16 Working on filtering and step resposnse
2016-02-17 Step response and fixed maxon code that was wrong for negative currents.
    [pru1_main.c]
2016-02-18 Working on motor stuff.
2016-02-19 Double 1st order filters
2016-06-01 First commit in long time. Will start edit after this commit.
    [error_analysis.ods]
2016-09-19 hardware added
    [FSR_amp_v0.1.brd, FSR_amp_v0.1.sch, ankleBot_v0.2.brd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]
2016-10-17 Updated motor driver so current to cmpvalue is better.
2016-10-17 Finishing new current 2 cmpValue code
2016-10-17 updated main with sineLUT and added printFloat2fix16
2016-10-20 Updated ufb to constant torque (current)
2016-10-26 Working on motor stuff
2016-10-26 added util functions for converting rpm and velocity bits
2016-10-27 Added motor vel to adc and working on fixing motor limit
    [pru1_main.c]
2017-04-11 IMU works, but cable lenght must remain short for i2c
    [pru1_main.c]
2017-08-10 Motor is not working with this commit, will co last working version
    [pru1_main.c]
2017-08-10 Fixed heelStrikeCheck to use for calibration of thresholds
2017-08-15 Fixed delay in the wrong direction
    [pru1_main.c]
2017-09-29 Changed name of device tree to be openwearable
2017-11-21 Starting dev on upper arm xo-skeleton
2017-11-22 adc driver and emg source
2017-11-29 Working on porting nonlinear bayes filter by Sanger
2017-11-29 nonlin bayes filter and filter testing code
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2018-02-15 Added filtertest to utils
2018-03-15 Clarity edits + solenoid driver (still working on it)
2018-04-06 Pressure sensors and valves
2018-04-06 sensors + valves working
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2018-05-30 stretch sensor plus misc stuff
2019-01-05 Working on bayes filter
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2019-01-07 Matlab version of bayes filter
2019-01-08 Bayes filter on PRUs
2019-01-08 Proto for bayes filter with decimation
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2019-01-26 Large update: progress on bayes filters + new logging and publishing methods
2019-05-15 Upgraded pam control w i2c mux
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2019-05-29 Device tree updates and debug pins
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2019-06-11 New makefile and some minor updates to drivers
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2019-07-31 updated i2c driver and added cpu loop support and added bno055 support from arm side
2019-08-05 Fixed segfault bug and added reflex module
    [pruloop.c]
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2019-08-14 script for pwm muxing and edits to source for pwm
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2019-09-29 updated reflex to include minimum sensing pressure, added sine to fix16, added freq sweeps for sys ID
    [pruloop.c]
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2019-10-04 updated haptics and sweeps and added tare encoder
2019-10-07 new app for haptuv evauations which includes a reflex instantiation, minor upgrades to reflex and device tree
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2019-12-04 Commit for s410 note that removed imu during exp
2022-07-13 fixed bugs in template
    [pruloop.c]
2022-09-08 Updated maxon motor and tare to use the PruLoadParams method
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2022-09-12 Updated haptic-tracking with new motor bias current argument
2022-10-03 Library edits -- adc current issue, increase size of log
2023-10-11 Added LUT capabilities -- fixed few bugs related to LUT memmap
    [pruloop.c]
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2024-10-13 Fixed bugs in new hx711 driver
    [pruloop.c]
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2025-05-02 Added dir for hardware/pcb
    [FSR_amp_v0.1.brd, FSR_amp_v0.1.sch, ankleBot_v0.2.brd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]
2025-05-02 Add ADC amplifier schematic and layout files
    [adc.brd, adc.sch]
2025-05-02 Add PAM controller board and schematic files
    [PAM Controller _ v3.brd, PAM Controller _ v3.sch]
2025-05-02 Add pam-controller board and schematic files.
    [pam-controller.brd, pam-controller.sch]
2025-07-11 sfm4100 massflow driver, working but only at low sampling rates
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2025-07-31 spi bus for ads131 -- not yet working
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2026-06-15 refactor(master): per-core library split (common/a8/pru) + minimal app set
    Bring the AM335x branch in line with the am64x architecture: split the flat
    library/ into per-core trees and pare the apps down to the template, laying a
    clean foundation for a public release.
    Library:
    - library/{include,src,pru_src}/ -> common/ (cross-core contract: mem_types.h,
    fix16.h, int64.h), a8/ (Cortex-A8 / Linux), pru/ (PRU firmware).
    - Drop dead files (.old/.hold/.example) and redundant .cmd copies.
    - rsc_table_pru{0,1}.h: drop vestigial "pru.h" include (matches am64x; uint32_t
    comes from rsc_types.h) so the PRU build needs no a8/ headers.
    Build:
    - Rewrite library + template Makefiles for the split lay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
    [pruloop.c]
2026-06-15 feat(log): binary packed logging + C decoder (replaces ASCII sprintf path)
    The A-core logger now writes fixed-size packed binary records instead of
    sprintf'd ASCII, with a self-describing header so logs decode offline.
    - format.h / format.c: per-app binary schema authority — FormatLogRecordBytes,
    FormatLogSchema (#fields / #record_bytes), FormatLogRecord (pack, no sprintf).
    - log.c LogNewFile: ASCII header (magic, date, fs_hz, malloc, schema) ending in
    a #DATA sentinel, then raw little-endian records.
    - log.c LogWriteStateToFile: pack records by pointer-advance — drops the
    per-sample sprintf and the O(n^2) strcat; DMA/memcpy write + stats unchanged.
    - utils/logdecode: standalone C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
2026-06-15 refactor(dma): extract EDMA3 backend into dma.c/dma.h (HAL split)
    Move the AM335x EDMA3 driver out of log.c into a dedicated dma.c behind an
    opaque dma.h interface (DmaInit / DmaInitialized / DmaTransfer / DmaCleanup).
    log.c is now board-agnostic: it calls the interface and never touches EDMA
    registers, so it can be kept byte-identical across branches — only the backend
    (EDMA3 here; J721E UDMA later) differs per SoC.
    Finishes what the am64x dma.h started (header extracted, impl left inline in
    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
2026-06-15 feat(log): ring-buffer + writer-thread logging (unbounded, SD-safe, hang fixed)
    Replace the preallocated-mmap log model with a producer/consumer design:
    - The real-time SIGALRM callback only packs records into a lock-free SPSC RAM
    ring (async-signal-safe: memcpy + atomics + sem_post); it never blocks.
    - A writer thread drains the ring to the file with write(). Disk/SD latency
    stays off the control loop; if the disk can't keep up the ring fills and
    records are dropped (counted) instead of stalling or crashing.
    Fixes three problems with the old mmap approach:
    - Unbounded run length. The old code mmap'd a fixed LOGSIZE (~320 MB) and
    advanced an offset with NO bounds check, so runs past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
2026-06-15 feat(params): parse fs from -c config in PruLoadParams
    PruLoadParams ignored its file argument and hardcoded fs_hz=1000. Parse the sample rate from the config file's first token (defaults are written first, so a missing/garbage value can't divide-by-zero in HZ_TO_TICKS). Also remove the dead commented-out copy of PruLoadParams from pru.c.
2026-06-15 test: add test/ infra + logbench logging-throughput benchmark
    New test/ tree mirrors apps/ but builds to test/bin (off $PATH) with a test-specific firmware suffix. Full-OW integration-test form; reserve host-unit tests for pure-host modules. logbench is DRY: pulls template's hooks via vpath and supplies only a headless uiloop.c + run_logbench.sh.
    Finds the A8 logging limit by ramping fs: ~18 kHz on boneblack, bounded by the fixed 200 Hz A8 drain of the 96-deep PRU state-ring (not disk; drops=0 through 50 kHz). Reports OK / SAMPLE-LOSS / DROPS.
2026-06-15 docs: add CLAUDE.md for the AM335x/main branch
    Adapted from the am64x branch's working notes to main's actual AM335x per-core layout (common/a8/pru), runtime (remoteproc1/2 = PRU0/1, 0x4A300000 SRAM base), the ring/thread binary logger + ~18 kHz 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
2026-06-15 refactor(pru): name remoteproc nodes via /dev/remoteproc symlinks (match am64x)
    Replace the hardcoded /sys/class/remoteproc/remoteprocN firmware/state paths with the friendly, stable /dev/remoteproc/pruss-core{0,1} symlinks, built into "<node>/firmware" and "<node>/state" like the am64x backend. The only per-board knobs are now the two node paths + firmware prefix (RP_PRU{0,1}_PATH / PRU_FW_PREFIX in pru.h), so pru.c is SoC-agnostic and can be kept identical across branches (PruMemMap aside).
    Also pull in am64x's PruWaitRunning so PruInit blocks until both cores report "running" before enabling (closes the memInit/pru_ctl cold-boot race). Validated on boneblack: PRUs start + 100% logbench c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
2026-06-15 refactor(pru): move board-specific paths to board.c as extern const
    Replace the RP_PRU{0,1}_PATH / PRU_FW_PREFIX header macros with real typed const objects (const char* const) defined in a new per-board board.c and declared extern in pru.h. pru.c references the objects, so it stays board-agnostic and byte-identical-able across branches (only board.c + pru.h's memory defines differ per SoC). A const object can't be defined in a shared header without multiple-definition errors, hence the dedicated TU.
    The app *.c wildcard picks up board.c automatically (no Makefile change). Validated on boneblack: PRUs start, 100% logbench capture, no regression. Control-word writer split deferred.
    Co-Autho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
2026-06-17 refactor(template): schema-driven log format, frame rename, PRU hook view/io split
    Three related cleanups to the template foundation:
    - log format: a per-app log is now one ow_schema[] table {name, type,
    offsetof(state_t, field)}. The generic library core (format_core.c) iterates
    it to pack the binary record, emit the self-describing #fields: header, and
    render the -v debug screen, so an app edits only the table. Type registry in
    format.h (OW_* incl. fix16 via fix16_to_float). Binary output byte-identical.
    - logdecode: carry #date: / #fs_hz: from the log header through to the CSV
    preamble so the decoded CSV is self-describing.
    - state: rename state_t.time -> frame (the field hol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
    [pruloop.c]
2026-07-07 feat(log): never overwrite an existing log file (auto-rename)
    LogNewFile now opens with O_EXCL instead of O_TRUNC; on a name clash it inserts
    "-1", "-2", ... before the extension until a free name is found (atomic via
    O_EXCL, no TOCTOU race) and reports the name actually used. No existing log is
    ever silently clobbered, with no caller changes -- a global safety net for
    every app.

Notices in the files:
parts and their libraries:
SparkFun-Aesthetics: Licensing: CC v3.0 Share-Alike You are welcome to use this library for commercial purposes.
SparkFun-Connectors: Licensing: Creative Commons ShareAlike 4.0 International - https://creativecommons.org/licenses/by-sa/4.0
